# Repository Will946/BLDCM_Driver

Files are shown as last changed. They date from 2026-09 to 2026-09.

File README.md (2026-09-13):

# BLDC Motor Controller

> [!NOTE]
> This project is currently in active development. Features and documentation are subject to change.

## Table of Contents
- [Project Overview](#project-overview)
- [Electronics](#electronics)
  - [MCU PCB (Top Board)](#mcu-pcb-top-board)
  - [Power PCB (Bottom Board)](#power-pcb-bottom-board)
  - [Complete Stack-Up](#complete-stack-up)
- [Results](#results)

---

## Project Overview

This project aims to develop a **high-precision Brushless DC (BLDC) motor controller** from scratch, covering both hardware and firmware aspects. The controller is designed for advanced motor control applications, leveraging a powerful STM32 microcontroller, a dedicated motor driver IC, and comprehensive sensing capabilities for precise operation and rotor position estimation.

The core of the system is a custom two-board stack: an MCU board housing the main control logic and a power board managing motor drive and sensing. The two boards connect through a Molex board-to-board stack connector, keeping the whole assembly compact enough to sit directly behind the motor.

<div align="center">
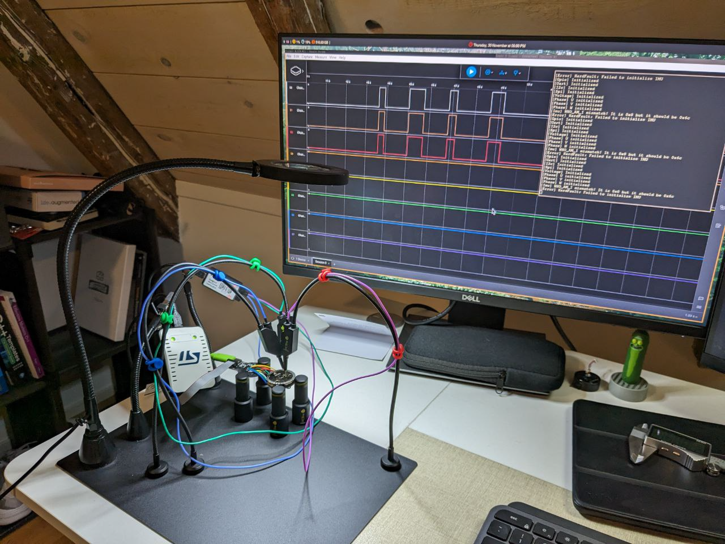
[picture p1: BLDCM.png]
Bench setup during firmware bring-up, oscilloscope showing PWM and phase signals
  
  &nbsp;&nbsp;
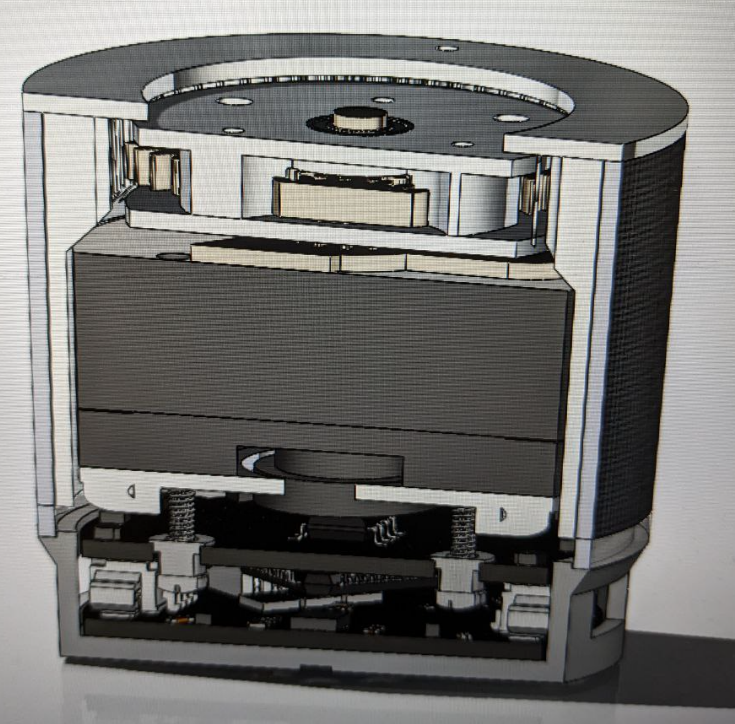
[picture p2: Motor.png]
3D model cross-section of the motor housing
  
</div>

---

## Electronics

The electronics consist of two interconnected custom-designed Printed Circuit Boards (PCBs), designed using **KiCad**. Both boards are **4-layer, circular designs** sized to fit inside the motor housing, and stack together through a **Molex board-to-board connector** that carries power, control signals, and communication lines between them.

### MCU PCB (Top Board)

The top PCB is the brain of the controller. It runs the control loop, reads all of the position/motion sensors, and exposes the debug and status interfaces a developer needs while bringing the system up.

<div align="center">
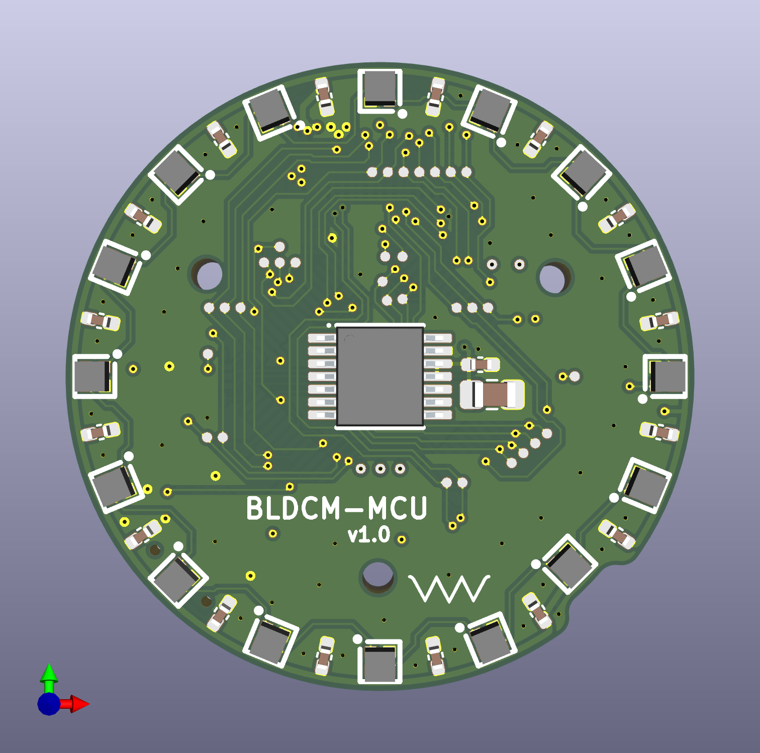
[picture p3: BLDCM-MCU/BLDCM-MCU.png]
MCU PCB top side render
  
  &nbsp;&nbsp;
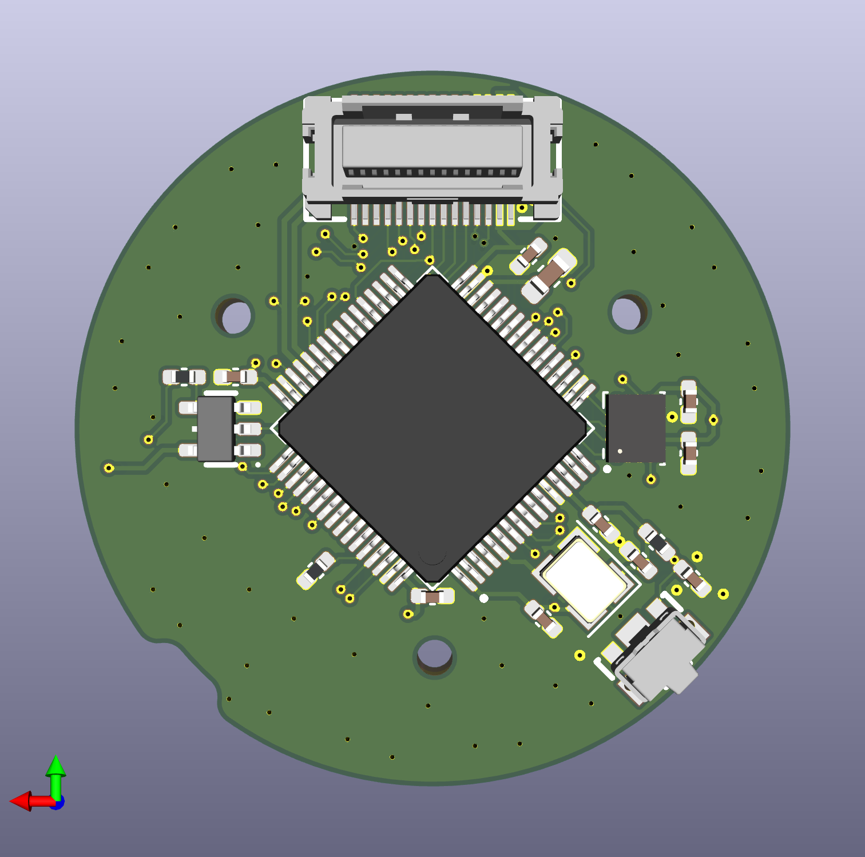
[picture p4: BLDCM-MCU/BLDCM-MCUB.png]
MCU PCB bottom side render
  
</div>

**How it works:**
- The **STM32F4 microcontroller** sits at the center of the board and runs the motor control algorithm (trapezoidal or FOC) in a fast timer-driven loop, reading sensor data and updating the PWM duty cycles sent down to the power board on every cycle.
- The **AS5048A** magnetic angle encoder reads the rotor's absolute position with 14-bit resolution off a magnet mounted on the motor shaft. This gives the controller true rotor position for commutation, rather than relying on back-EMF sensing, which matters a lot at low speed and standstill.
- The **ISM330DHCX IMU** adds acceleration and angular velocity data from the board itself, which is useful for detecting external motion or vibration and for any application where the motor's own orientation/movement (not just the rotor's) needs to be tracked.
- An **SK6805 RGB LED ring** wraps around the board's edge and is driven per-LED to show system status (idle, running, fault, etc.) at a glance without needing a debugger attached.
- A **reset button** is broken out on the edge for quick resets during bring-up and testing.
- The top-side connector routes down to the power board through the Molex stack connector, carrying the PWM/gate signals, sensor feedback, and shared power rails between the two boards.

### Power PCB (Bottom Board)

The bottom PCB handles everything high-current: driving the motor phases, sensing voltage and current, and providing the external connectivity for power and communication.

<div align="center">
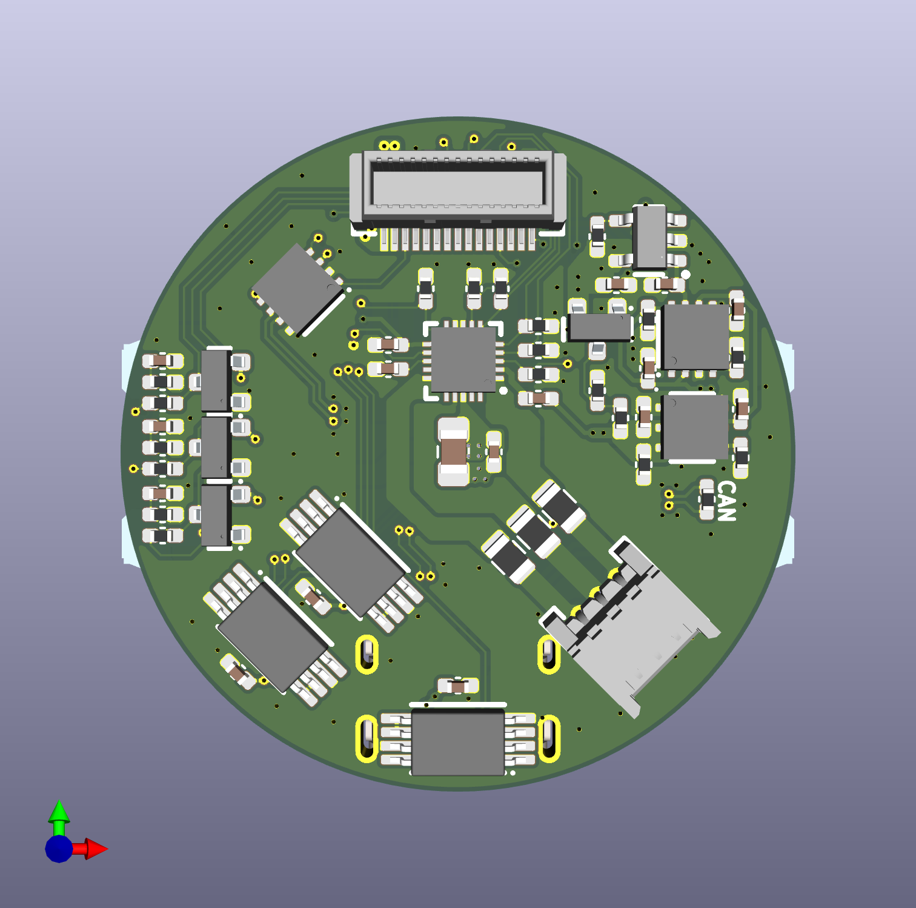
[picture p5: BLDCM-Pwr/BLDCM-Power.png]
Power PCB top side render
  
  &nbsp;&nbsp;
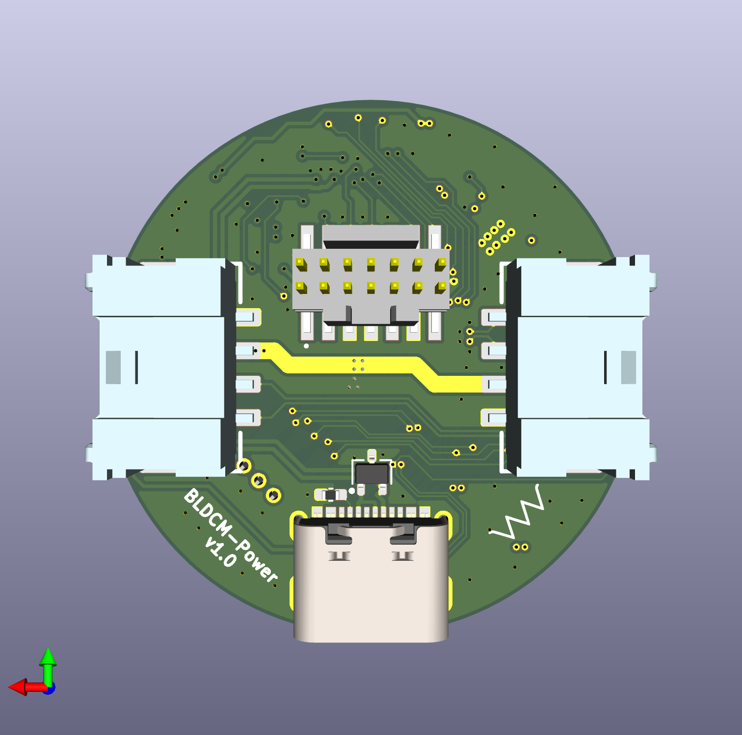
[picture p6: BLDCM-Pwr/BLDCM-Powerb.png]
Power PCB bottom side render
  
</div>

**How it works:**
- The **TMC6300** is a fully integrated 3-phase gate driver/MOSFET bridge. It takes the PWM commutation signals from the MCU board and switches the three motor phases directly — there's no separate discrete MOSFET stage, which keeps the board small enough to fit the round form factor.
- Three **INA240** current sense amplifiers measure the current on each motor phase in real time. This phase current feedback is what the FOC algorithm on the MCU board needs to run its current control loops (the Park/Clarke transforms depend on accurate, low-noise current readings).
- Four voltage sensing networks monitor the **DC bus voltage** plus all **three phase voltages** (after filtering), letting the firmware detect undervoltage/overvoltage conditions and, combined with the current sensing, estimate power delivered to the motor.
- The **TCAN1462** CAN FD transceiver lets multiple motor controllers be **daisy-chained together on a single CAN bus**, so a single host can address and command several motors (e.g. in a multi-joint robot) over one pair of wires.
- A **J-Link 14-pin SWD connector** breaks out the STM32's debug port for flashing and live debugging with a J-Link probe.
- A **USB-C connector** provides Full-Speed USB for data logging, host-side control, and can also be used to supply power to the board during bench testing.
- Two **4-pin Molex Micro-Lock Plus connectors** on the sides carry motor power and CAN out to the next board in the chain, using a locking, vibration-resistant connector rather than a bare header.

---

### Complete Stack-Up

The MCU and Power boards aren't independent — they're designed as a single functional unit that happens to be split across two PCBs, connected face-to-face by the Molex board-to-board connector so the whole stack fits behind the motor in a slim, cylindrical footprint.

- **Control signal path:** the STM32 on the MCU board computes the commutation state (trapezoidal or FOC) and outputs PWM/gate-control signals, which cross the stack connector down to the TMC6300 driver on the Power board. The TMC6300 does the actual high-current switching of the three motor phases.
- **Feedback path:** the Power board's three INA240 current sense amplifiers and four voltage sensing networks measure what's actually happening on the phases and DC bus, and that analog/digital feedback travels back up across the same connector to the STM32's ADCs, closing the current and voltage control loops each control cycle.
- **Position feedback stays local:** the AS5048A encoder and ISM330DHCX IMU are both on the MCU board, next to the STM32, so rotor position and motion data never have to cross the board-to-board connector — only the commutation output and phase feedback do.
- **Shared power rails:** the Power board is where motor power and USB-C power come in; the regulated logic rails needed by the MCU board are distributed up through the stack connector, so only one board needs external power wiring.
- **External I/O lives on the Power board:** USB-C, the CAN bus (for daisy-chaining multiple controllers), and the J-Link SWD debug header are all broken out on the Power board's edge, since that's the board facing the outside of the housing — while status (LED ring) and reset live on the MCU board, which faces the user/inspection side.

In short: the Power board is the "muscle and senses" (driving the motor, measuring current/voltage, talking to the outside world), and the MCU board is the "brain" (running the control algorithm and tracking rotor position) — the stack connector is what ties the two into one closed-loop controller.

---

## Results

Below are some pictures/video taken during development, showing the bench setup used to bring up the firmware (reading out PWM and phase signals on the oscilloscope) and a cross-section render of the motor housing. The controller design and calibration procedures will be explained in depth in the future :)

<div align="center">

**[▶ Watch the test video](BLDCTest.mp4)**

</div>

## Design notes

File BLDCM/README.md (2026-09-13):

# BLDCM KiCad Library

Welcome to my personal collection of KiCad library files. This repository is designed for my own use but is publicly available. It includes custom schematic symbols, PCB footprints, and associated 3D models.

---

## 📚 Library Contents

This library (`BLDCM`) contains the following components:

### Schematic Symbols

Here are the custom symbols available in the `BLDCM.kicad_sym` library.

| Symbol | Description | Default Footprint |
| :--- | :--- | :--- |
| **AS5048A** | Magnetic Rotary Encoder 14-Bit | `BLDCM:TSSOP-14` |
| **BAT54S** | SMD Small Signal Schottky Diodes | `BLDCM:SOT-23` |
| **C** | Unpolarized capacitor | `BLDCM:C_0402` |
| **D_Schottky** | Schottky Diode | - |
| **D_Schottky_B0520LW** | Schottky Diode | `BLDCM:SOD-123` |
| **ECS-3225MVLC-240-CN** | Crystal Oscillator 24MHz ±25ppm | `BLDCM:Crystal_3225` |
| **ESDA25W** | ESD suppressors / TVS diodes 25V 400W Unidirect | `BLDCM:SOT-323` |
| **GND** | Ground power symbol | - |
| **INA239-Q1** | High-Precision Power Monitor With SPI Interface | `BLDCM:VSSOP-10` |
| **INA240AXPW** | Ultra-Precise Current Sense Amplifier | `BLDCM:TSSOP-8` |
| **ISM330DHCX** | iNEMO Inertial Measurement Unit (IMU) | `BLDCM:LGA-14L` |
| **JLINK_14P_FTSH-107-01-L-DV-K-TR** | J-Link 14-Pin STMicroelectronics standard | `BLDCM:FTSH-107-01-L-DV-K-TR` |
| **LDL212PV33R** | LDO Voltage Regulator 1.2A 3.3V | `BLDCM:DFN-6-2x2` |
| **LDLN030G33R** | LDO Voltage Regulator 300mA 3.3V Ultra-Low Noise | `BLDCM:TSOT-23-5` |
| **LDO40LPU50RY** | LDO Voltage Regulator 400mA 5V | `BLDCM:DFN-6-3x3` |
| **LED_SK6805-EC15** | Addressable RGB LED 1.5x1.5mm | `BLDCM:LED-1515` |
| **MT6701** | Hall-Based Angle Position Encoder Sensor | `BLDCM:SOP-8` |
| **Molex_05MM-30P** | Molex SlimStack Connector 0.5mm 30-pin | `BLDCM:501920-3001` |
| **Molex_05MM-30P-F** | Molex SlimStack Receptor 0.5mm 30-pin | `BLDCM:52991-0308` |
| **Molex_125MM-3P-H** | Molex PicoBlade Connector 1.25mm 3-pin RA | `BLDCM:53048-0310` |
| **Molex_125MM-4P-H-SMD** | Molex PicoBlade Connector 1.25mm 4-pin RA SMD | `BLDCM:53261-0471` |
| **Molex_MicroLock_2MM-2R-4P-H-SMD** | Molex Micro-Lock Plus Header 2.0mm 4-pin Dual Row RA | `BLDCM:220205-0471` |
| **Molex_MicroLock_2MM-4P-H-SMD** | Molex Micro-Lock Plus Header 2.0mm 4-pin Single Row RA | `BLDCM:505578-0460` |
| **R** | Resistor | `BLDCM:R_0402` |
| **R_KRL1220** | Current Sense Resistor SMD 0.3W 50mOhm 1% | `BLDCM:KRL1220` |
| **SN74LV1T34** | Single Buffer GATE CMOS Logic Level Shifter | `BLDCM:SOT-23-5` |
| **STM32F446RE** | STM32F446RE Microcontroller | `BLDCM:LQFP64` |
| **Switch_EVP-AKE31A** | Side-operational SMD Light Touch Switch | `BLDCM:EVPAKE31A` |
| **TCAN1462** | CAN FD Transceiver | `BLDCM:VSON-8` |
| **TMC6300-LA** | Motor Driver for 3-Phase BLDC/PMSM | `BLDCM:QFN-20` |
| **TP** | Test Point | `BLDCM:TP_0.5mm` |
| **TPS2115ADRB** | Two-Input, One-Output Power Multiplexer | `BLDCM:VSON-8` |
| **TPS2121** | 2.8V to 22V Priority Power MUX | `BLDCM:VQFN-HR-12` |
| **USB_12402012E212A** | Amphenol USB 2.0 Type C Connector | `BLDCM:12402012E212A` |
| **USB_217179-0001** | Molex USB 2.0 Type C Connector | `BLDCM:217179-0001` |
| **VDD** | Source power symbol | - |

<br>

### PCB Footprints & 3D Models

The following footprints are available in the `BLDCM.pretty` library. Almost all footprints have a corresponding 3D model in the `BLDCM.3dshapes` directory.

| Footprint | Description | Has 3D Model? |
| :--- | :--- | :---: |
| **12402012E212A** | Amphenol USB Type-C Connector, 16-pin | ✅ |
| **217179-0001** | Molex USB Type-C Connector, 16-pin | ✅ |
| **220205-0471** | Molex Micro-Lock Plus Header, 2mm, 4-pin, Dual Row, RA | ✅ |
| **501920-3001** | Molex SlimStack Board-to-Board Connector, 0.5mm, 30-pin | ✅ |
| **505578-0460** | Molex Micro-Lock Plus Header, 2mm, 4-pin, Single Row, RA | ✅ |
| **52991-0308** | Molex SlimStack Board-to-Board Receptor, 0.5mm, 30-pin | ✅ |
| **53048-0310** | Molex PicoBlade Header, 1.25mm, 3-pin, RA | ✅ |
| **53261-0471** | Molex PicoBlade Header, 1.25mm, 4-pin, RA, SMD | ✅ |
| **C_0201, C_0402, C_0603, C_0805** | SMD Capacitor Packages | ✅ |
| **Crystal_3225** | SMD Crystal, 3.2x2.5 mm | ✅ |
| **DFN-6-2x2, DFN-6-3x3** | Dual Flat No-Lead Packages, 6-pin | ✅ |
| **EVPAKE31A** | Panasonic Side-operational Tactile Switch | ✅ |
| **FTSH-107-01-L-DV-K-TR** | Samtec FTSH Header, 1.27mm, 14-pin | ✅ |
| **KRL1220** | ROHM Current Sense Resistor, 1220 package | ✅ |
| **LED-1515** | SMD LED, 1.5x1.5 mm | ✅ |
| **LGA-14L** | Land Grid Array Package, 14-pin | ✅ |
| **LQFP64** | Low-profile Quad Flat Package, 64-pin | ✅ |
| **QFN-20** | Quad Flat No-Lead Package, 20-pin | ✅ |
| **R_0201, R_0402, R_0603, R_0805, R_1210** | SMD Resistor Packages | ✅ |
| **SOD-123** | Small Outline Diode Package | ✅ |
| **SOP-8** | Small Outline Package, 8-pin | ✅ |
| **SOT-23, SOT-23-5, SOT-323** | Small Outline Transistor Packages | ✅ |
| **TP_0.5mm, TP_1.0mm, TP_2.0mm** | Circular Test Point Pads | ❌ |
| **TSOT-23-5** | Thin Small Outline Transistor Package, 5-pin | ✅ |
| **TSSOP-8, TSSOP-14** | Thin-Shrink Small Outline Packages | ✅ |
| **VQFN-HR-12** | Very-thin Quad Flat No-Lead Package, 12-pin | ✅ |
| **VSON-8** | Very-thin Small Outline No-Lead Package, 8-pin | ✅ |
| **VSSOP-10** | Very-thin-Shrink Small Outline Package, 10-pin | ✅ |

---

## 🚀 Getting Started (Adding to KiCad)

To use this library in your KiCad projects, follow these steps:

1.  **Clone or Download:** Get a local copy of this repository.

2.  **Configure KiCad Paths:**
    * Open KiCad and go to `Preferences` -> `Configure Paths...`.
    * Click the `+` icon to add a new path.
    * Set the **Name** to `BLDCM_DIR` and the **Path** to the location where you cloned the repository.

3.  **Add Symbol Library:**
    * Go to `Preferences` -> `Manage Symbol Libraries...`.
    * Select the 'Global Libraries' or 'Project Specific Libraries' tab.
    * Click the folder icon to "Add existing library" and select the `BLDCM.kicad_sym` file from the repository folder.

4.  **Add Footprint Library:**
    * Go to `Preferences` -> `Manage Footprint Libraries...`.
    * Select the 'Global Libraries' or 'Project Specific Libraries' tab.
    * Click the folder icon and select the `BLDCM.pretty` directory from the repository folder.

The new symbols and footprints will now be available in the KiCad editors!

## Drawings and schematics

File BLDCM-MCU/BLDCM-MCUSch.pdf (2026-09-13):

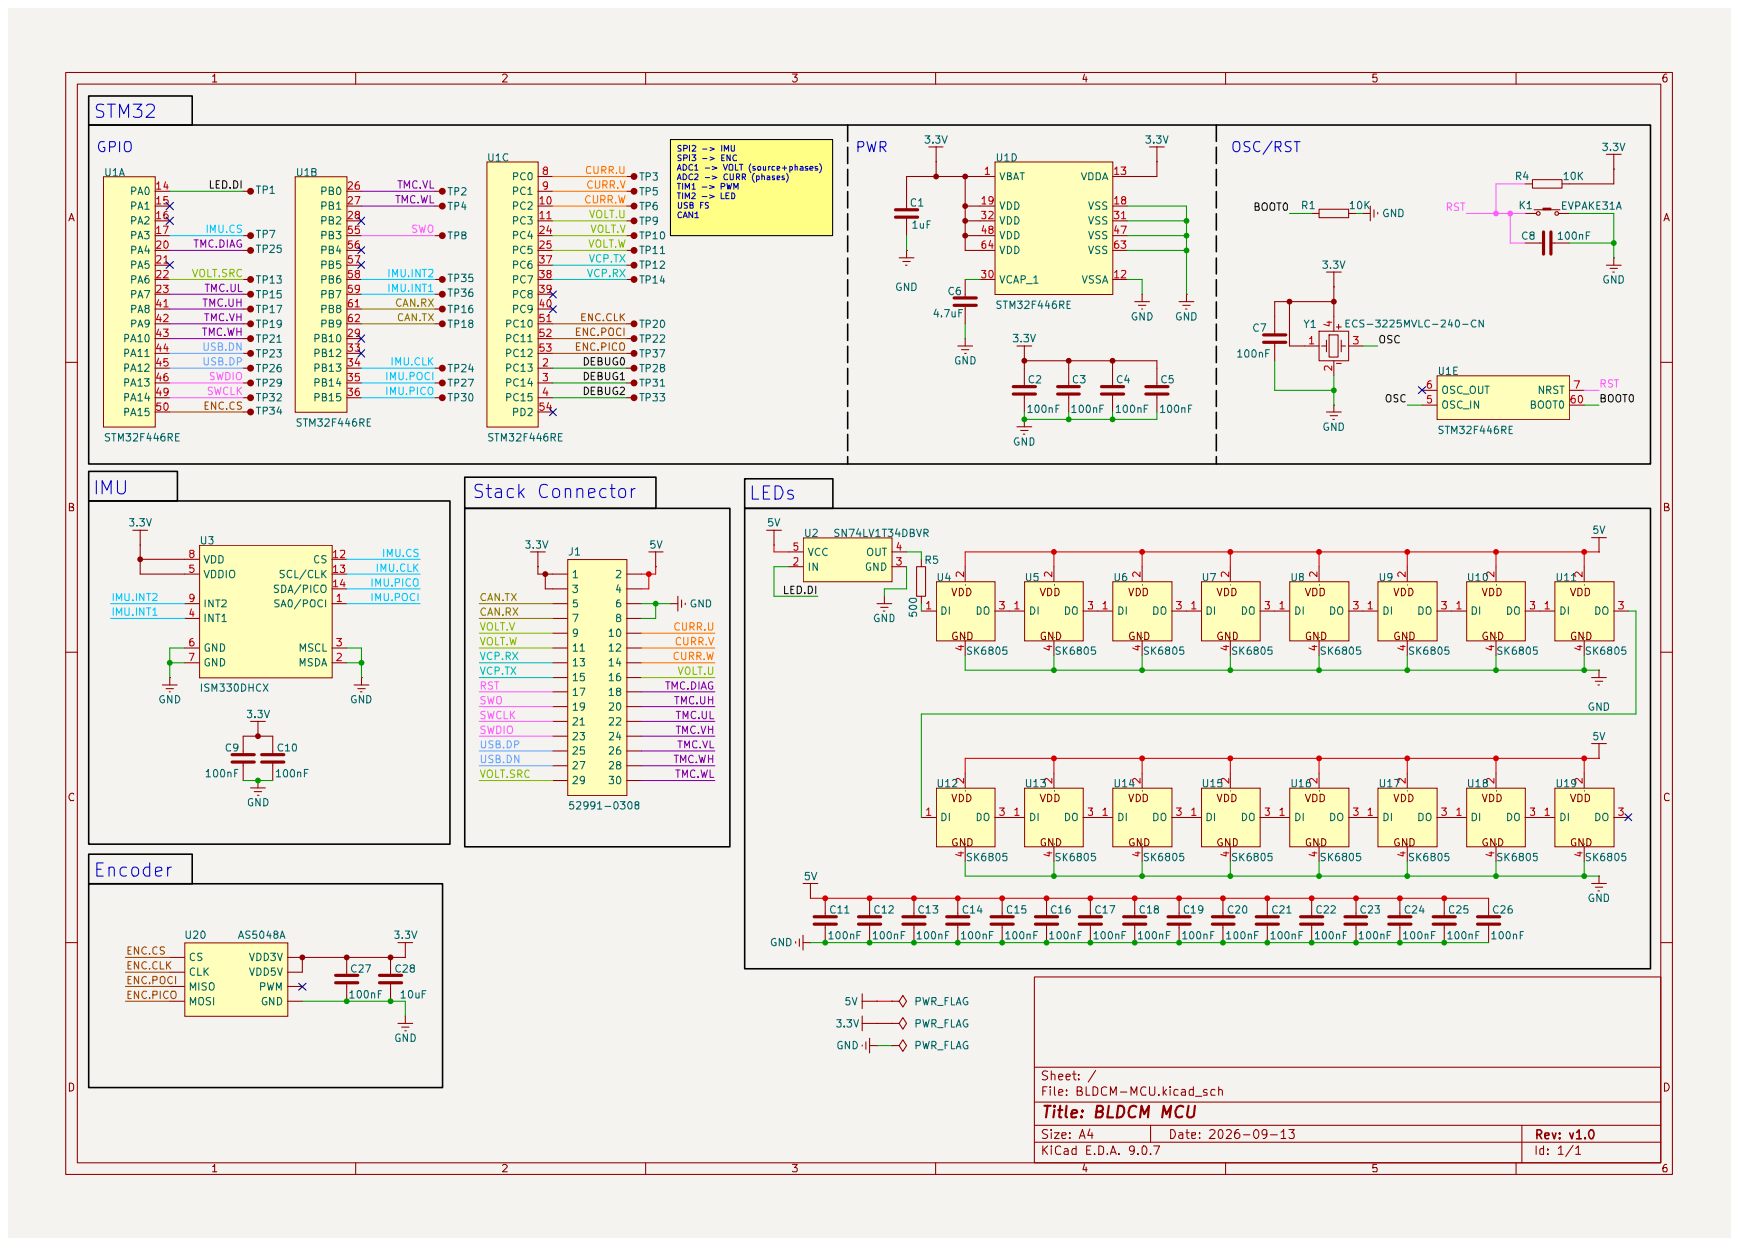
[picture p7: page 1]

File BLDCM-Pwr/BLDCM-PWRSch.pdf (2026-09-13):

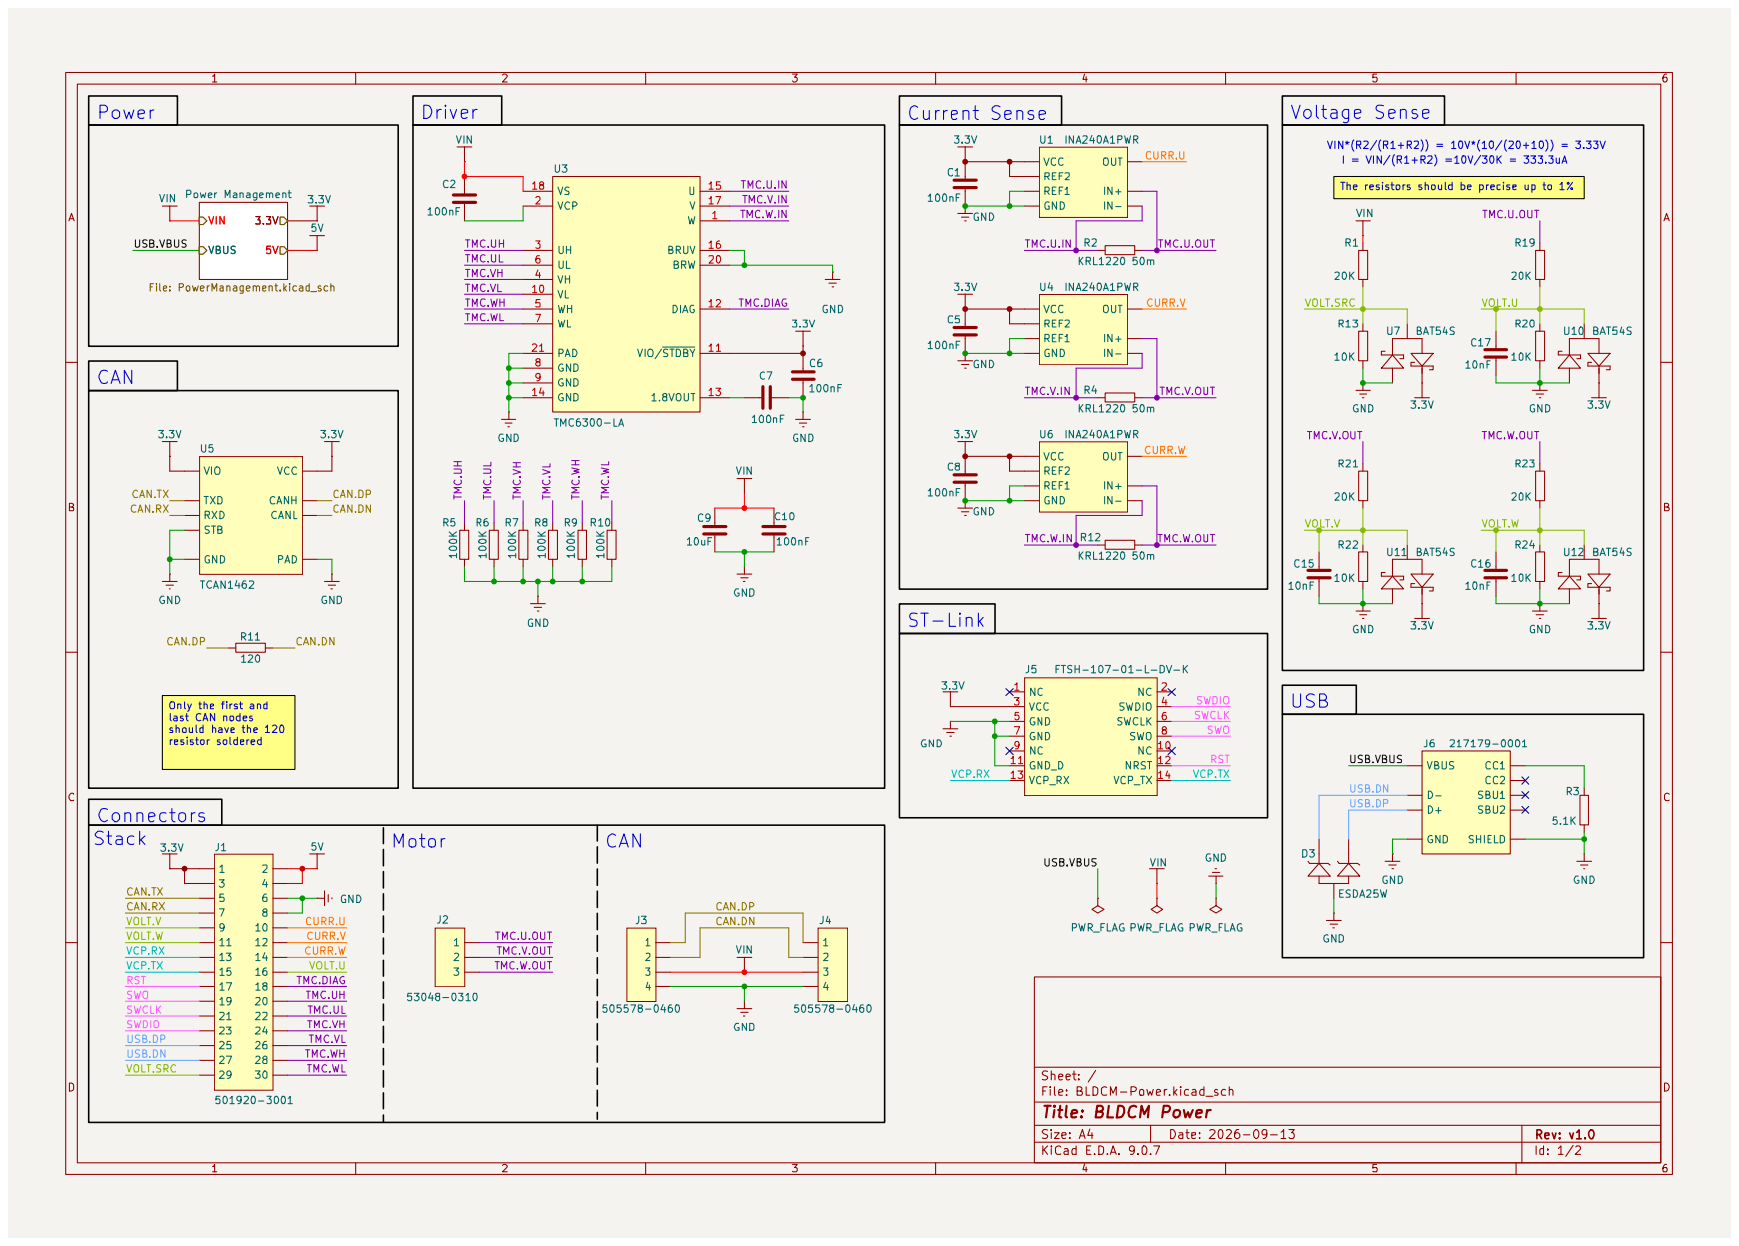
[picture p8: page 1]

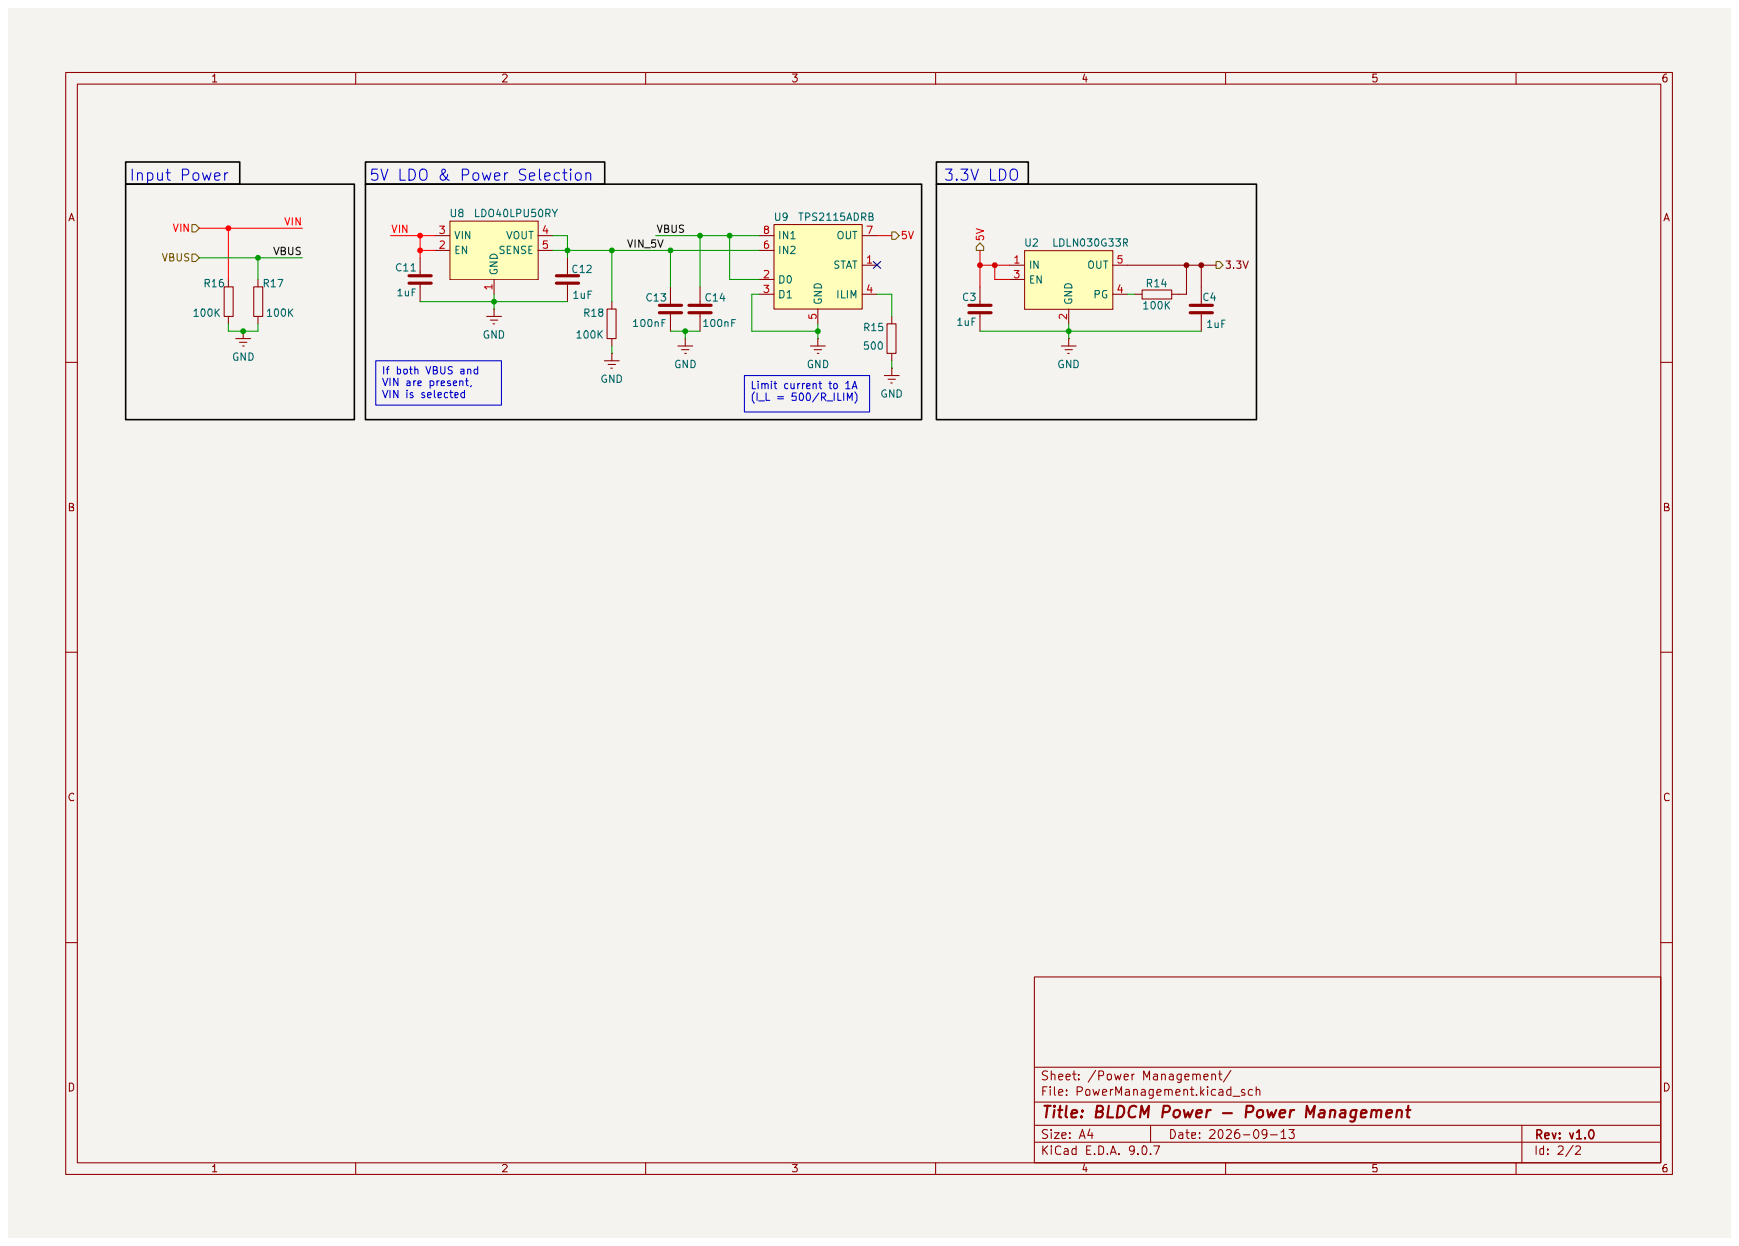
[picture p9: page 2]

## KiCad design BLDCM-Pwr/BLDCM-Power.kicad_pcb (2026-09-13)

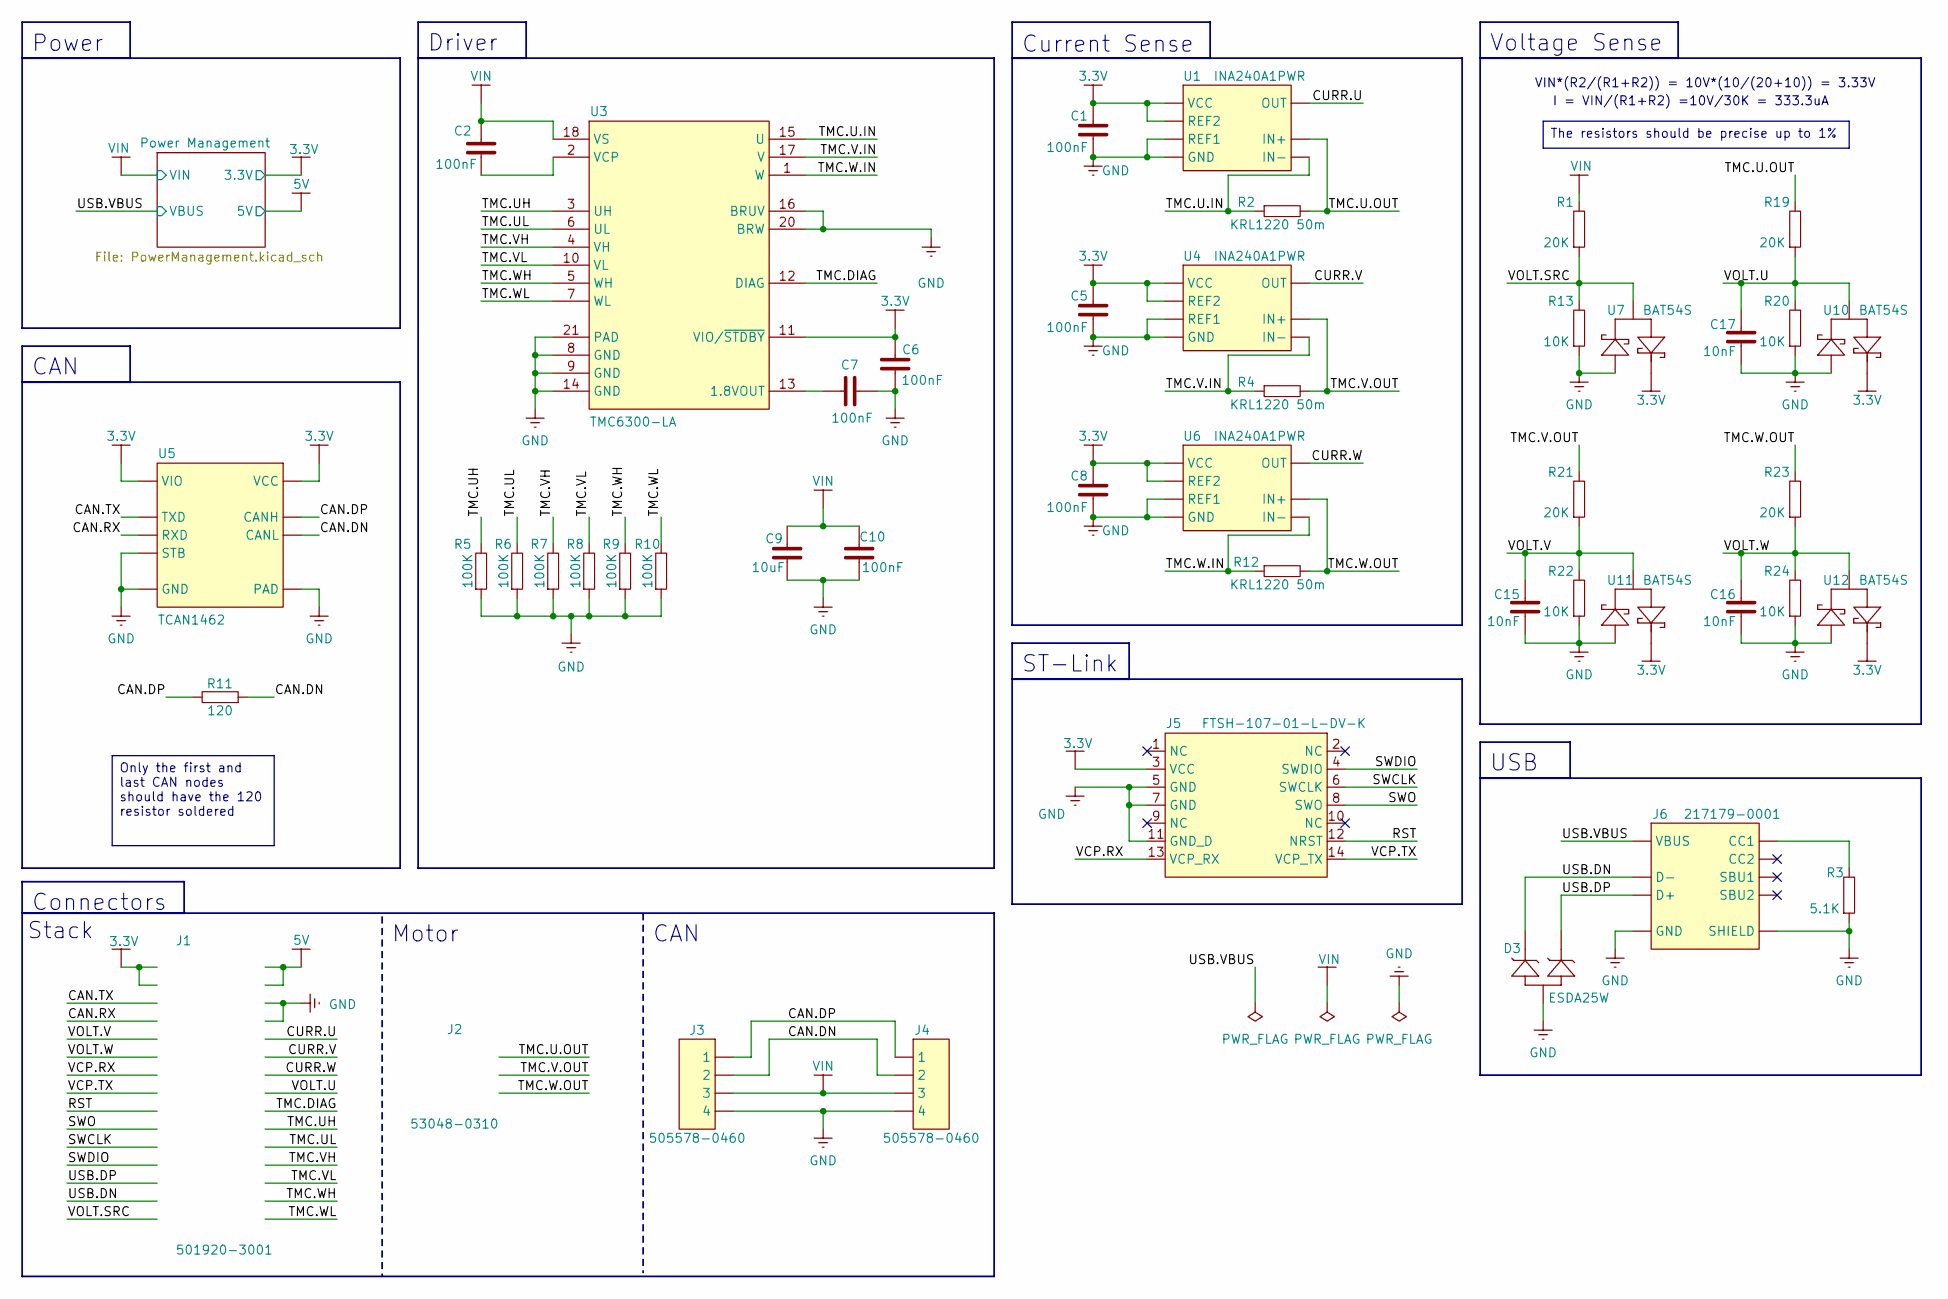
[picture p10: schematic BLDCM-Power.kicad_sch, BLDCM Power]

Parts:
C1, C2, C5, C6, C7, C8, C10: 100nF; C_0402
C9: 10uF; C_0402
C15, C16, C17: 10nF; C_0402
D3: ESDA25W; SOT-323
J1: 501920-3001
J2: 53048-0310
J3, J4: 505578-0460
J5: FTSH-107-01-L-DV-K; FTSH-107-01-L-DV-K-TR
J6: 217179-0001
R1, R19, R21, R23: 20K; R_0402
R2, R4, R12: KRL1220 50m; KRL1220
R3: 5.1K; R_0402
R5, R6, R7, R8, R9, R10: 100K; R_0402
R11: 120; R_0402
R13, R20, R22, R24: 10K; R_0402
U1, U4, U6: INA240A1PWR; TSSOP-8
U3: TMC6300-LA; QFN-20
U5: TCAN1462; VSON-8
U7, U10, U11, U12: BAT54S; SOT-23

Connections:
3.3V: C1.1, C5.1, C6.2, C8.1, J1.1, J1.3, J5.3 (VCC), U1.5 (VCC), U1.6 (REF2), U3.11 (VIO/~STDBY), U4.5 (VCC), U4.6 (REF2), U5.3 (VCC), U5.5 (VIO), U6.5 (VCC), U6.6 (REF2), U7.2, U10.2, U11.2, U12.2; also elsewhere on the board
5V: J1.2, J1.4; also elsewhere on the board
/CAN.DN: J3.2, J4.2, R11.1, U5.6 (CANL)
/CAN.DP: J3.1, J4.1, R11.2, U5.7 (CANH)
/CAN.RX: J1.7, U5.4 (RXD)
/CAN.TX: J1.5, U5.1 (TXD)
/CURR.U: J1.10, U1.8 (OUT)
/CURR.V: J1.12, U4.8 (OUT)
/CURR.W: J1.14, U6.8 (OUT)
/RST: J1.17, J5.12 (NRST)
/SWCLK: J1.21, J5.6 (SWCLK)
/SWDIO: J1.23, J5.4 (SWDIO)
/SWO: J1.19, J5.8 (SWO)
/TMC.DIAG: J1.18, U3.12 (DIAG)
/TMC.U.IN: R2.1, U1.3 (IN-), U3.15 (U)
/TMC.U.OUT: J2.1, R2.2, R19.2, U1.2 (IN+)
/TMC.UH: J1.20, R5.2, U3.3 (UH)
/TMC.UL: J1.22, R6.2, U3.6 (UL)
/TMC.V.IN: R4.1, U3.17 (V), U4.3 (IN-)
/TMC.V.OUT: J2.2, R4.2, R21.2, U4.2 (IN+)
/TMC.VH: J1.24, R7.2, U3.4 (VH)
/TMC.VL: J1.26, R8.2, U3.10 (VL)
/TMC.W.IN: R12.1, U3.1 (W), U6.3 (IN-)
/TMC.W.OUT: J2.3, R12.2, R23.2, U6.2 (IN+)
/TMC.WH: J1.28, R9.2, U3.5 (WH)
/TMC.WL: J1.30, R10.2, U3.7 (WL)
/USB.DN: D3.1, J1.27, J6.A7 (D-), J6.B7 (D-2)
/USB.DP: D3.2, J1.25, J6.A6 (D+), J6.B6 (D+2)
/VCP.RX: J1.13, J5.13 (VCP_RX)
/VCP.TX: J1.15, J5.14 (VCP_TX)
/VOLT.SRC: J1.29, R1.1, R13.2, U7.3
/VOLT.U: C17.2, J1.16, R19.1, R20.2, U10.3
/VOLT.V: C15.2, J1.9, R21.1, R22.2, U11.3
/VOLT.W: C16.2, J1.11, R23.1, R24.2, U12.3
GND: C1.2, C5.2, C6.1, C7.1, C8.2, C9.1, C10.1, C15.1, C16.1, C17.1, D3.3, J1.6, J1.8, J3.4, J4.4, J5.5 (GND), J5.7 (GND), J5.11 (GND_D), J6.A1_B12 (GND), J6.B1_A12 (GND), J6.SH1 (SHIELD), J6.SH2 (SHIELD), J6.SH3 (SHIELD), J6.SH4 (SHIELD), R3.1, R5.1, R6.1, R7.1, R8.1, R9.1, R10.1, R13.1, R20.1, R22.1, R24.1, U1.4 (GND), U1.7 (REF1), U3.8 (GND), U3.9 (GND), U3.14 (GND), U3.16 (BRUV), U3.20 (BRW), U3.21 (PAD), U4.4 (GND), U4.7 (REF1), U5.2 (GND), U5.8 (STB), U5.PAD, U6.4 (GND), U6.7 (REF1), U7.1, U10.1, U11.1, U12.1; also elsewhere on the board
unnamed: J6.A5 (CC1), R3.2
unnamed: C7.2, U3.13 (1.8VOUT)
unnamed: C2.1, U3.2 (VCP)
VBUS: J6.A4_B9 (VBUS), J6.B4_A9 (VBUS); also elsewhere on the board
VIN: C2.2, C9.2, C10.2, J3.3, J4.3, R1.2, U3.18 (VS); also elsewhere on the board

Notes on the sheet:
ST-Link
I = VIN/(R1+R2) =10V/30K = 333.3uA
Driver
Stack
Power
CAN
VIN*(R2/(R1+R2)) = 10V*(10/(20+10)) = 3.33V
Motor
Voltage Sense
USB
Connectors
Current Sense
The resistors should be precise up to 1%
Only the first and last CAN nodes should have the 120 resistor soldered

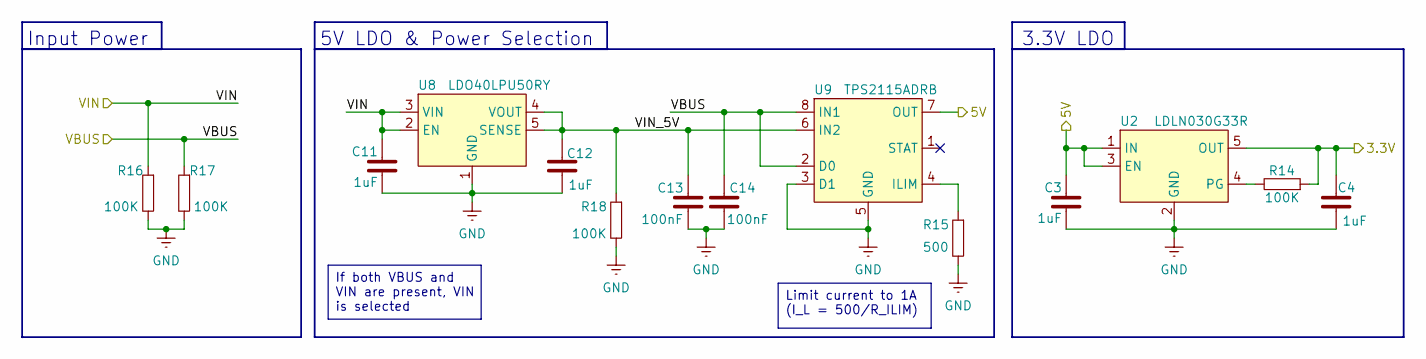
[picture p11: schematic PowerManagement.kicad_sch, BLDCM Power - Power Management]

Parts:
C3, C4, C11, C12: 1uF; C_0402
C13, C14: 100nF; C_0402
R14, R16, R17, R18: 100K; R_0402
R15: 500; R_0402
U2: LDLN030G33R; TSOT-23-5
U8: LDO40LPU50RY; DFN-6-3x3
U9: TPS2115ADRB; VSON-8

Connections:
3.3V: C4.2, R14.1, U2.5 (OUT); also elsewhere on the board
5V: C3.2, U2.1 (IN), U2.3 (EN), U9.7 (OUT); also elsewhere on the board
/Power Management/VIN_5V: C12.2, C13.1, R18.1, U8.4 (VOUT), U8.5 (SENSE), U9.6 (IN2)
GND: C3.1, C4.1, C11.1, C12.1, C13.2, C14.2, R15.2, R16.2, R17.2, R18.2, U2.2 (GND), U8.1 (GND), U8.PAD, U9.3 (D1), U9.5 (GND), U9.PAD; also elsewhere on the board
unnamed: R14.2, U2.4 (PG)
unnamed: R15.1, U9.4 (ILIM)
VBUS: C14.1, R17.1, U9.2 (D0), U9.8 (IN1); also elsewhere on the board
VIN: C11.2, R16.1, U8.2 (EN), U8.3 (VIN); also elsewhere on the board

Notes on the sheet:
Input Power
3.3V LDO
5V LDO & Power Selection
Limit current to 1A (I_L = 500/R_ILIM)
If both VBUS and VIN are present, VIN is selected

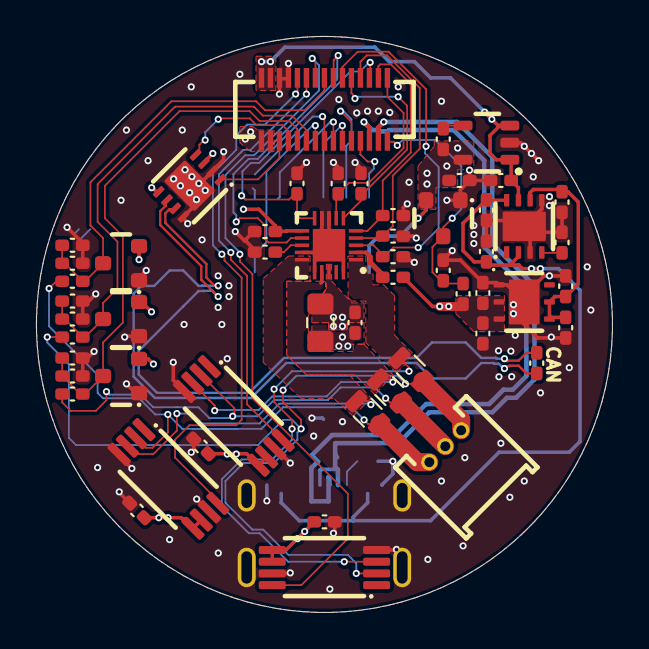
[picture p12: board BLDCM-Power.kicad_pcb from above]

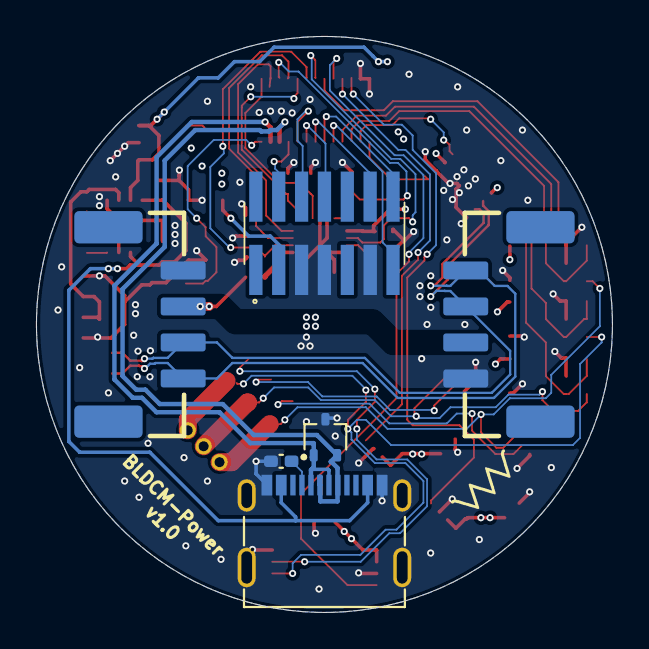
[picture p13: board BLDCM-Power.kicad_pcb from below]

Board: 4 copper layers, 32.0 x 32.0 mm, 60 parts (6 on the bottom side), 43 nets.

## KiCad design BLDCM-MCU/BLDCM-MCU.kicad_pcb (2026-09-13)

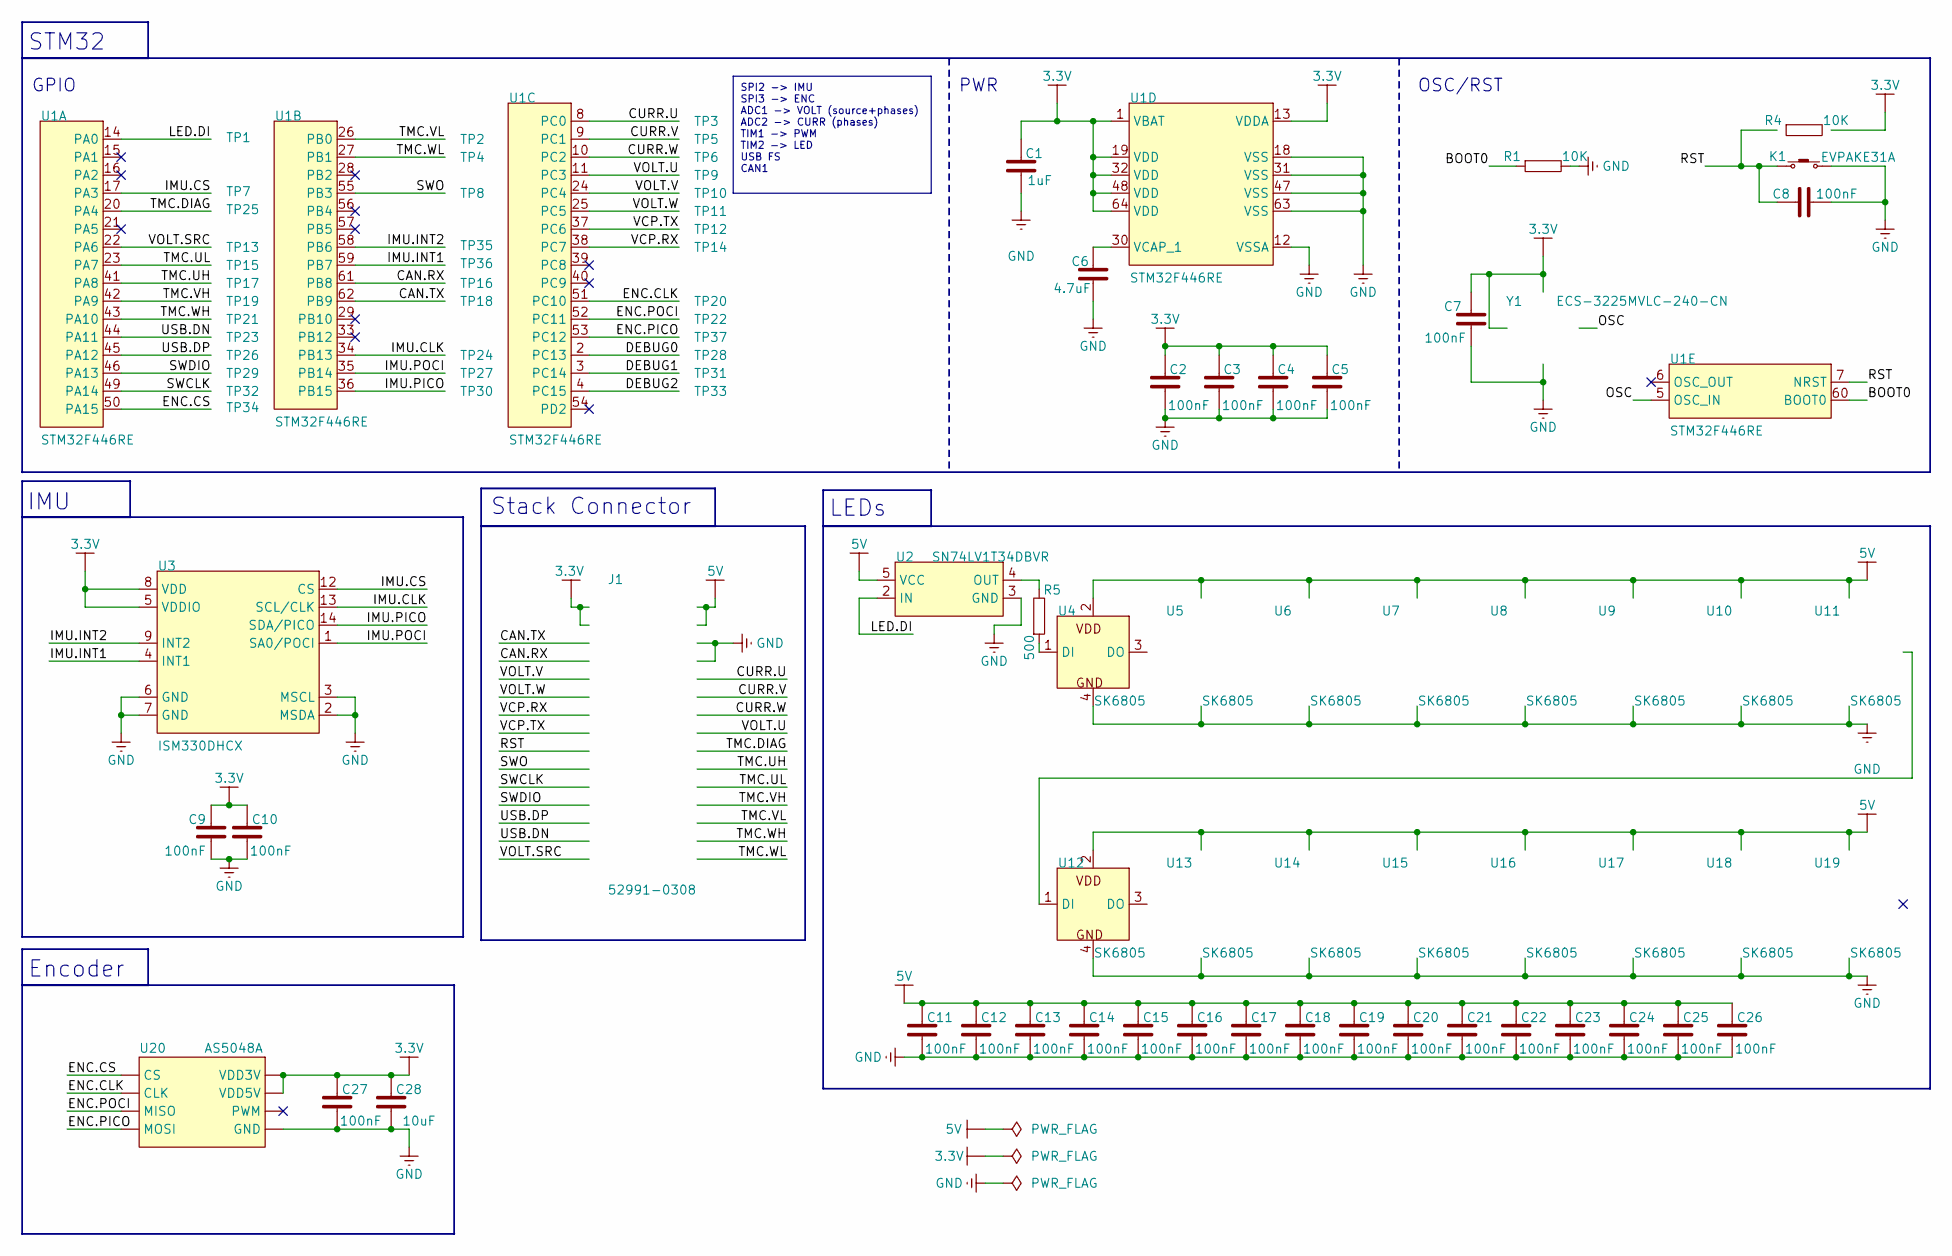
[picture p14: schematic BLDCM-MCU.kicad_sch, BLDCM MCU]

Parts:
C1: 1uF; C_0402
C2, C3, C4, C5, C7, C8, C9, C10, C11, C12, C13, C14, C15, C16, C17, C18, C19, C20, C21, C22, C23, C24, C25, C26, C27: 100nF; C_0402
C6: 4.7uF; C_0402
C28: 10uF; C_0402
J1: 52991-0308
K1: EVPAKE31A
R1, R4: 10K; R_0402
R5: 500; R_0402
TP1, TP2, TP3, TP4, TP5, TP6, TP7, TP8, TP9, TP10, TP11, TP12, TP13, TP14, TP15, TP16, TP17, TP18, TP19, TP20, TP21, TP22, TP23, TP24, TP25, TP26, TP27, TP28, TP29, TP30, TP31, TP32, TP33, TP34, TP35, TP36, TP37: Test point 0.5mm; TP_0.5mm
U1: STM32F446RE; LQFP64
U2: SN74LV1T34DBVR; SOT-23-5
U3: ISM330DHCX; LGA-14L
U4, U5, U6, U7, U8, U9, U10, U11, U12, U13, U14, U15, U16, U17, U18, U19: SK6805; LED-1515
U20: AS5048A; TSSOP-14
Y1: ECS-3225MVLC-240-CN; Crystal_3225

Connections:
3.3V: C1.2, C2.2, C3.2, C4.2, C5.2, C7.2, C9.2, C10.2, C27.2, C28.2, J1.1, J1.3, R4.2, U1.1 (VBAT), U1.13 (VDDA), U1.19 (VDD), U1.32 (VDD), U1.48 (VDD), U1.64 (VDD), U3.5 (VDDIO), U3.8 (VDD), U20.11 (VDD5V), U20.12 (VDD3V), Y1.1, Y1.4
5V: C11.2, C12.2, C13.2, C14.2, C15.2, C16.2, C17.2, C18.2, C19.2, C20.2, C21.2, C22.2, C23.2, C24.2, C25.2, C26.2, J1.2, J1.4, U2.5 (VCC), U4.2 (VDD), U5.2 (VDD), U6.2 (VDD), U7.2 (VDD), U8.2 (VDD), U9.2 (VDD), U10.2 (VDD), U11.2 (VDD), U12.2 (VDD), U13.2 (VDD), U14.2 (VDD), U15.2 (VDD), U16.2 (VDD), U17.2 (VDD), U18.2 (VDD), U19.2 (VDD)
/BOOT0: R1.1, U1.60 (BOOT0)
/CAN.RX: J1.7, TP16.1, U1.61 (PB8)
/CAN.TX: J1.5, TP18.1, U1.62 (PB9)
/CURR.U: J1.10, TP3.1, U1.8 (PC0)
/CURR.V: J1.12, TP5.1, U1.9 (PC1)
/CURR.W: J1.14, TP6.1, U1.10 (PC2)
/DEBUG0: TP28.1, U1.2 (PC13)
/DEBUG1: TP31.1, U1.3 (PC14)
/DEBUG2: TP33.1, U1.4 (PC15)
/ENC.CLK: TP20.1, U1.51 (PC10), U20.2 (CLK)
/ENC.CS: TP34.1, U1.50 (PA15), U20.1 (CS)
/ENC.PICO: TP37.1, U1.53 (PC12), U20.4 (MOSI)
/ENC.POCI: TP22.1, U1.52 (PC11), U20.3 (MISO)
/IMU.CLK: TP24.1, U1.34 (PB13), U3.13 (SCL/CLK)
/IMU.CS: TP7.1, U1.17 (PA3), U3.12 (CS)
/IMU.INT1: TP36.1, U1.59 (PB7), U3.4 (INT1)
/IMU.INT2: TP35.1, U1.58 (PB6), U3.9 (INT2)
/IMU.PICO: TP30.1, U1.36 (PB15), U3.14 (SDA/PICO)
/IMU.POCI: TP27.1, U1.35 (PB14), U3.1 (SA0/POCI)
/LED.DI: TP1.1, U1.14 (PA0), U2.2 (IN)
/OSC: U1.5 (OSC_IN), Y1.3
/RST: C8.2, J1.17, K1.1, R4.1, U1.7 (NRST)
/SWCLK: J1.21, TP32.1, U1.49 (PA14)
/SWDIO: J1.23, TP29.1, U1.46 (PA13)
/SWO: J1.19, TP8.1, U1.55 (PB3)
/TMC.DIAG: J1.18, TP25.1, U1.20 (PA4)
/TMC.UH: J1.20, TP17.1, U1.41 (PA8)
/TMC.UL: J1.22, TP15.1, U1.23 (PA7)
/TMC.VH: J1.24, TP19.1, U1.42 (PA9)
/TMC.VL: J1.26, TP2.1, U1.26 (PB0)
/TMC.WH: J1.28, TP21.1, U1.43 (PA10)
/TMC.WL: J1.30, TP4.1, U1.27 (PB1)
/USB.DN: J1.27, TP23.1, U1.44 (PA11)
/USB.DP: J1.25, TP26.1, U1.45 (PA12)
/VCP.RX: J1.13, TP14.1, U1.38 (PC7)
/VCP.TX: J1.15, TP12.1, U1.37 (PC6)
/VOLT.SRC: J1.29, TP13.1, U1.22 (PA6)
/VOLT.U: J1.16, TP9.1, U1.11 (PC3)
/VOLT.V: J1.9, TP10.1, U1.24 (PC4)
/VOLT.W: J1.11, TP11.1, U1.25 (PC5)
GND: C1.1, C2.1, C3.1, C4.1, C5.1, C6.1, C7.1, C8.1, C9.1, C10.1, C11.1, C12.1, C13.1, C14.1, C15.1, C16.1, C17.1, C18.1, C19.1, C20.1, C21.1, C22.1, C23.1, C24.1, C25.1, C26.1, C27.1, C28.1, J1.6, J1.8, K1.2, R1.2, U1.12 (VSSA), U1.18 (VSS), U1.31 (VSS), U1.47 (VSS), U1.63 (VSS), U2.3 (GND), U3.2 (MSDA), U3.3 (MSCL), U3.6 (GND), U3.7 (GND), U4.4 (GND), U5.4 (GND), U6.4 (GND), U7.4 (GND), U8.4 (GND), U9.4 (GND), U10.4 (GND), U11.4 (GND), U12.4 (GND), U13.4 (GND), U14.4 (GND), U15.4 (GND), U16.4 (GND), U17.4 (GND), U18.4 (GND), U19.4 (GND), U20.13 (GND), Y1.2
unnamed: C6.2, U1.30 (VCAP_1)
unnamed: R5.2, U2.4 (OUT)
unnamed: R5.1, U4.1 (DI)
unnamed: U4.3 (DO), U5.1 (DI)
unnamed: U5.3 (DO), U6.1 (DI)
unnamed: U6.3 (DO), U7.1 (DI)
unnamed: U7.3 (DO), U8.1 (DI)
unnamed: U8.3 (DO), U9.1 (DI)
unnamed: U9.3 (DO), U10.1 (DI)
unnamed: U10.3 (DO), U11.1 (DI)
unnamed: U11.3 (DO), U12.1 (DI)
unnamed: U12.3 (DO), U13.1 (DI)
unnamed: U13.3 (DO), U14.1 (DI)
unnamed: U14.3 (DO), U15.1 (DI)
unnamed: U15.3 (DO), U16.1 (DI)
unnamed: U16.3 (DO), U17.1 (DI)
unnamed: U17.3 (DO), U18.1 (DI)
unnamed: U18.3 (DO), U19.1 (DI)

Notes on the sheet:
STM32
IMU
LEDs
Stack Connector
Encoder
OSC/RST
GPIO
PWR
SPI2 -> IMU SPI3 -> ENC ADC1 -> VOLT (source+phases) ADC2 -> CURR (phases) TIM1 -> PWM TIM2 -> LED USB FS CAN1

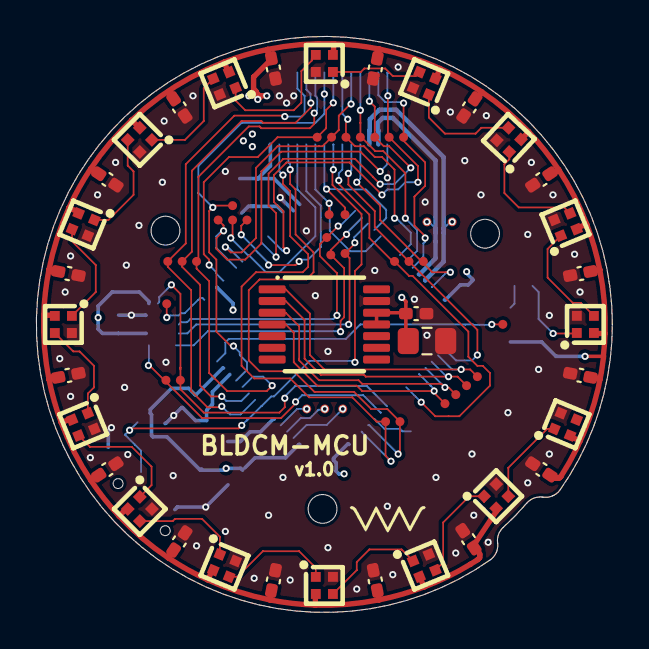
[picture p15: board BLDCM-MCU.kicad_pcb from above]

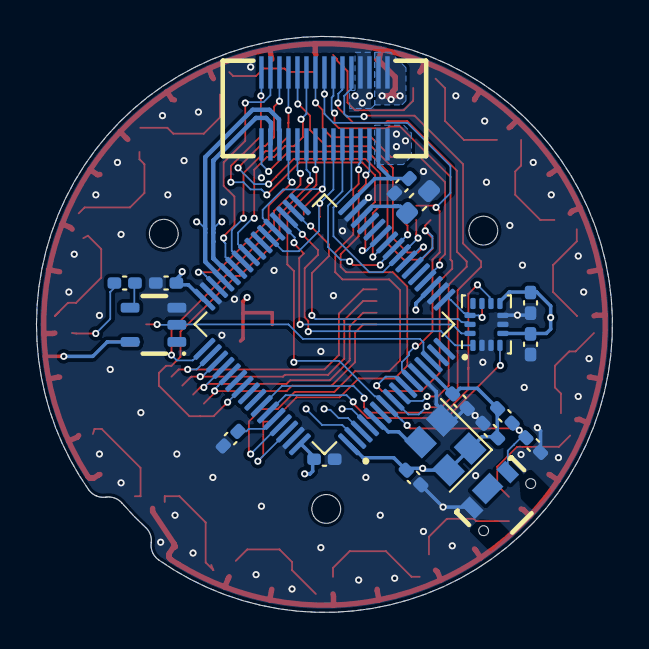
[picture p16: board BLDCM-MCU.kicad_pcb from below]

Board: 4 copper layers, 32.0 x 32.0 mm, 91 parts (19 on the bottom side), 61 nets.
